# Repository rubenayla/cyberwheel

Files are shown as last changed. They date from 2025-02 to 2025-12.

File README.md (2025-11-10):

<p align="center">
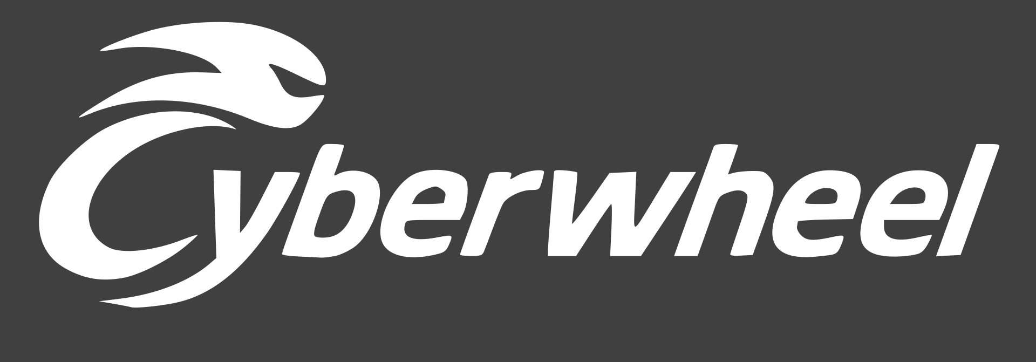
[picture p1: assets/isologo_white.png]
Cyberwheel Logo
  
</p>

# CYBERWHEEL

Open-source electric unicycle hardware and firmware.

## 📖 Documentation

Visit our documentation site: **[https://rubenayla.github.io/cyberwheel/](https://rubenayla.github.io/cyberwheel/)**

## 🎥 Pitch Video

Watch our project pitch: **[https://youtu.be/mN5FoosNMC0](https://youtu.be/mN5FoosNMC0)**

## Purpose
Make electric unicycles that are reliable for everyday use: waterproof, impact-resistant, durable over time, and easy to repair.

For this, create an open-source community to design both the Hardware and Firmware, so they can be repaired and modified, free of proprietary restrictions.

## Repository Structure

```
cyberwheel/
├── docs/              # MkDocs documentation source
├── cad/               # CAD files and designs
├── releases/          # Release versions (cw1.0, cw1.1, etc.)
├── battery/           # Battery design files and images
├── assets/            # Images and media
└── references/        # Reference materials and datasheets
```

## Development

### Build documentation locally

```bash
# Install dependencies with uv
uv sync

# Serve docs locally
uv run mkdocs serve

# Build static site
uv run mkdocs build
```

Documentation is automatically deployed to GitHub Pages on push to main.

## License

This project is licensed under the MIT License - see the [LICENSE](LICENSE) file for details.

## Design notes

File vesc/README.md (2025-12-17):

# VESC workspace

Working area for VESC electronics (Little FOCer, balance app, etc). Use this folder for configs, firmware packages, wiring notes, and raw logs. Anything meant for the published site can live in `docs/vesc/` and link back here.

Suggested layout
- `configs/` — VESC Tool motor/app exports plus a short note on firmware/tool version and hardware.
- `firmware/` — downloaded firmware/tool installers, note the matching hardware target (e.g., Little FOCer ≈ VESC 75_300/LFV3).
- `wiring/` — pinouts, harness drawings, connector part numbers.
- `logs/` — RT data, fault dumps, CSV captures.
- `scripts/` — helpers for converting/analyzing configs.

Naming for configs
- `motor-config_<hardware>_<fw>_<date>.xml`
- `app-config_<mode>_<fw>_<date>.xml`
Example: `motor-config_little-focer-v3.1_5.02_2025-03-28.xml`.

Mac + Little FOCer quick notes
- Install VESC Tool for macOS from vesc-project.com; match tool/firmware versions.
- Power the ESC, connect USB-C, pick `/dev/tty.usb*` in VESC Tool, connect, verify hardware before flashing.
- Start with the stable firmware noted in `stuff.md` (v5.02 for Little FOCer V3.1); keep a copy in `firmware/` with a README stating source/version.

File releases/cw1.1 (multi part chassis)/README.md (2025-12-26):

- think about lid assembly from top to bottom
- add platen to screw to pedal hangers
- finish transparent panel section
- add screws

# Data
Distance between pedal hangers is 5in = 127mm

## Dimensions (from cad/equations.txt)
- wheel_space: 80mm (compatible with 2.75in = 69.85mm tires)
- chassis_length: 360mm
- pedal_separation: 84mm
- seal_edge: 18mm
- wheel_diam: 16in
- thick: 2mm
- chassis_height: 240mm
- lid_height: 360mm
- lid_length: 240mm
- side: 60mm

# Current test setup (2025-03)
- Wheel: 16" (~406mm) hub motor
- Battery: 16S pack (test build; 20S is future design)
- Controller: Little FOCer V3.1, FW 6.05

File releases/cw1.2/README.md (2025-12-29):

# cw1.2

## Added parts
- Power pads by CDoucet: https://www.printables.com/model/698500-power-pads-for-euc/files

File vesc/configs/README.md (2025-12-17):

# Configs

Store VESC Tool exports here:
- Motor config XML
- App config XML (balance/PPM/UART/etc.)

For each file, note firmware version, VESC Tool version, hardware revision, motor, and date. Keep a short changelog if you iterate.

XML vs C headers
- Use XML for normal backup/restore and sharing with VESC Tool.
- C header exports are only needed if you embed configs into firmware builds. If you’re not compiling custom firmware, skip the C header saves.

Current files (2025-03):
- `vesc_mcconf.xml`: pulled from Little_FOCer_V3_1 running FW 6.05 (BLE). Note: limits are placeholder (e.g., l_max_vin=57V) and app mode is not balance; treat as “pre-cleanup” reference only.
- `vesc_appconf.xml`: pulled from same session; app_to_use=3 (PPM), not balance. Use as reference, not as a good baseline.

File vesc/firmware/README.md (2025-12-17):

# Firmware

Keep downloaded firmware, tool installers, and USB drivers here with source/URL and date. Label hardware targets clearly (Little FOCer ≈ VESC 75_300/LFV3 target).

Included (Mac):
- `macOS_VCP_Driver/SiLabsUSBDriverDisk.dmg` (Silicon Labs CP210x VCP driver installer, May 2025) and release notes.
  - Approval: In System Settings → Privacy & Security → Driver Extensions, ensure `CP210xVCPDriver (com.silabs.cp210x)` is enabled after install; allow “Silicon Laboratories Inc.” if prompted, then reboot.

Tip: store the exact VESC Tool version used to flash configs so you can reproduce results.

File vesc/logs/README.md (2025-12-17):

# Logs

Store RT data, fault dumps, CSV captures, and screenshots. Note firmware, tool version, hardware, and conditions (battery voltage, motor, load) for each capture.

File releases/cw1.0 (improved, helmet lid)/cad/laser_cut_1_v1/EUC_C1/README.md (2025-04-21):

- material: acero
    > acero porque es barato y fácil de soldar
- espesor: 2mm
- dimensiones: 653x507mm
- longitud total corte aprox: 4640mm
- plegados, todos a 90º:
    - 6 de 400mm
    - 8 de 210mm
- 1 unidad
- ningún acabado especial

# Estimación coste gpt
| Concepto | Parámetros | Cálculo | Coste (€) |
|:---|:---|:---|:---:|
| Material (acero 2 mm) | 47 €/m² | 0.653×0.507 = 0.331 m² → 0.331×47 | 15.56 |
| Corte láser | 50 €/h; 3 500 mm/min | 4 640 mm / 3 500 mm/min = 1.33 min → 1.33/60×50 | 1.11 |
| Plegado | 50 €/h; 1 min por doblez | 14 dobleces = 14 min → 14/60×50 | 11.67 |
| **Subtotal** | | | 28.34 |
| Overhead & margen (30%)| | 28.34×0.30 | 8.50 |
| **Total aproximado**  | | | **36.8**  |

Incluyendo transporte + IVA ~= 60€

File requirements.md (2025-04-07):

# Cyberwheel Design Requirements
## Concept
> WE SHOULD NOT BLAME THE RIDER FOR A SUDDEN UNPREDICTABLE CUTOFF OF THE EUC.
- Foolproof, weatherproof
- Impossible to fry electronics by riding hard
- Impossible to damage battery by riding too cold (leanback and emergency before)
- Leanback angle calculation is central point, function of:
    - Temperatures
    - Voltages
    - Currents
    - As a consequence:
        - Speed
    > To maintain a given guaranteed minimum torque
- Make it perform strict self-tests
- Error states:
    - **Warning**: Just so you know
    - **Alert**: Gradual limits that affect the performance when balancing. Affects leanback
        - Battery overheating, overvoltage, or undervoltage. All will limit the speed. Overheating may limit it to 0.
    - **Emergency**: STOP. Hard leanback. Safety measures
    > For molicel p42a pack: <8.4A, <4.2V, >0ºC, <45ºC. Gradual transfer curve when getting close to these limits, that results in gradual predictable leanback

## Hardware
- The charger will be built into the EUC, with a small vacuum cleaner style cable.
- Crimped connectors?
    > Not just soldered when there’s so much vibration.
- Bolts: Positive locking mechanism
    - > cotter pin, safety wiring, [nylon, prevailing torque, jet, K] lock nuts, tab washers or locking plates.
- Several wires in parallel for redundancy (motor and battery wiring), while being able to detect a single one disconnecting?
    > Maybe unnecessarily complex
- Battery disconnect loop key? (actionable from the outside.)

## Firmware
- Include emergency modes that get triggered for many reasons
- Dynamic calculation of max speed based on battery level, temperature, and other factors.
- Gradual tiltback that asympotically grows in intensity as the max speed is reached.
- 

- State machine?
    - OFF (Not balancing, when put sideways)
    - Balancing (Normal, affected by alerts)
    - Charging
    - Emergency (Balancing but with hard leanback, to speed 0)

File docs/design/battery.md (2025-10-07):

# Battery - Power and Charging

## CHARACTERISTICS
Battery specifications

- ABSOLUTE LIMITS - **20S2P PACK** - Voltage, Current, Temperature
    - The firmware may put other limits depending on voltage, current, and temperature, but these are the limits that won't be exceeded under any condition.
    - **84V** (4.2V * 20), max voltage * series
    - **90A** battery flow (45A * 2), max cont discharge current * parallels (will be limited to a fraction. Charging max is 25A, so probably about 60A discharge)
    - Charge: **16.8A** (8.4A*2), **1.41kW**
    - Discharge: **90A, 7.56kW**
        - Probably limited to **60A, 5kW** for standard BMS

- CELL LIMITS - SAFETY HOLY GRAIL:
    - **Operating Temp: $0ºC$ to $45ºC$**
    - Max continuous charging current: $8.4A$ (-max torque -max speed)
    - MOLICEL INR-21700-P42A ($60=50;=5*3*2*2$)
        - [INR-21700-P42A_datasheet.pdf](../assets/datasheets/INR-21700-P42A_datasheet.pdf)
        - [Detailed datasheet](https://www.molicel.com/wp-content/uploads/INR21700P42A-V4-80092.pdf)
        - LiNiMnCoO2 (NMC) cathode
        - Impedance at 10A DC 1s: $10 m\Omega$
        - $15.5$Wh, $4.2$Ah, $2.5V - 3.6V - 4.2V, 16m\Omega$
        - Discharge:
            - Continuous: `30A`
            - Peak: `45A`
        - Charge (<8.4A, <4.2V):
            - Max continuous: `8.4A`, 2C $(\frac{8.4A}{4.2Ah} = 2h^{-1})$
    - **Max peak charging pulse**:
        - [INR-21700-P42A_power_pulse.pdf](../assets/datasheets/INR-21700-P42A_power_pulse.pdf)

## PACK
- Energy: $40 * 15.5Wh = 620Wh$
- Max continuous power discharge at 3.6V: $40 * 3.6V * 30A = 4320W \approx 6$CV
- Max charge power at 85%SOC, 40ºC: $40 * 4V * 4.2A = 672W$
- EUC Range: $672Wh / 32.5Wh/km = 20km$
    - Current efficiency: $32.5$Wh/km = $117$J/m = $3.25 \frac{kWh}{100km}$

## FIRE
- [FB4LF-500 encapsulator agent, 4L to 1.8kWh](https://youtu.be/NkH7TzFtSP0?si=DRWmJS_XxrlnIuxk)
- [EUC FIRE](https://youtu.be/Oa79go_aUfc)
- https://everythingelectricunicycle.com/electric-unicycle-fire-risk-and-possible-causes-solutions/
- Fire retardant casing (LithiumPrevent):
    - robnor resin to prevent fire.
- Seriously protect + - separation of cells
- Standards to meet:
    - UL94 V-0 for the minimum used material thickness
    - FAR 25.853(a)(1)(i)

## Battery construction diagram and assembly calculations

- 20S3P, **20S2P**, 30S2P
- Estimated lateral space left for the batteries = (Total Width without ankle padding - Wheel hole width - 4 * chassis_thickness - 2 * padding) / 2 = $(200 - 3*25.4 - 4*3 - 2 * 3)/2 = 52.9mm$, so `math.floor(52.9/21) = math.floor(2.52) = 2`. Two layers of stacked cells
- Dimensions of cell pack (20S2P): `10*23 x 2*23 x 2*70 = 230 x 46 x 140 mm`

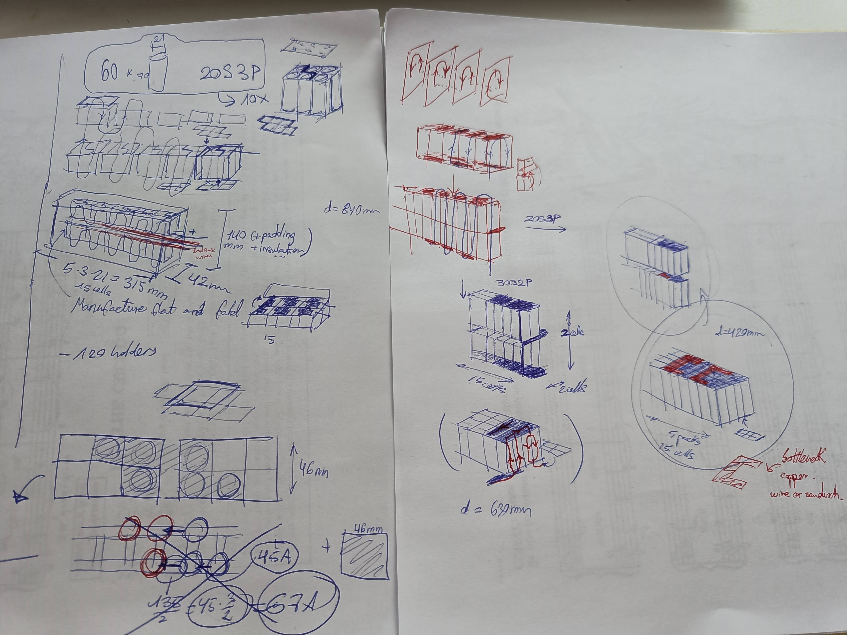
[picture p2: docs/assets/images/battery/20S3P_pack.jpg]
20S3P pack layout

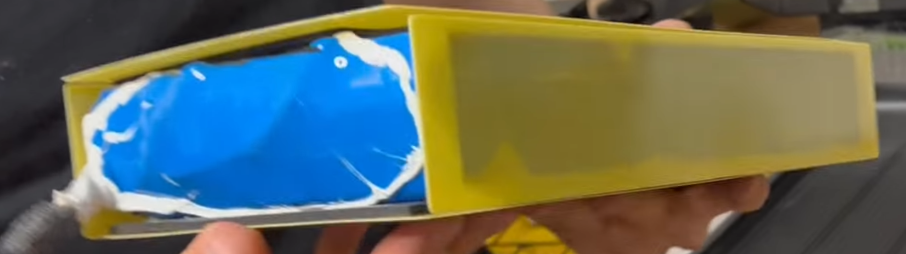
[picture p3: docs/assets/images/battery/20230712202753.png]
Begode EX20S Battery


- Small fans inside the pack

## Cell connection methods
- ~~Bus bars~~ (Hard to connect to the bus bar, hard to assemble)
- ~~Nickel Strip (Spot Welded)~~ (0.15x20mm just 20A, I need 135A)
- **Braided Copper Wire** soldered over Nickel strip
- ~~Busbar Connectors~~ (My cells are not compatible with them)
- **Copper Nickel Sandwich**
    - https://endless-sphere.com/sphere/threads/copper-nickel-sandwich-buses-for-series-connections.108006/
    - The nickel is the resistance that heats up, the current goes through the copper, heat accumulates at the contact points with the nickel, all metal melts, which allows the copper to also connect with the aluminum of the cell terminal below.
- ~~Copper Nickel busbar (tab sheet)~~ (About 150€)
    - Copper with small sections of nickel spot welded where each cell goes. I just have to cut it, place it, and spot-weld it like nickel strips, but with the higher current capacity.

## Braided Copper Wire

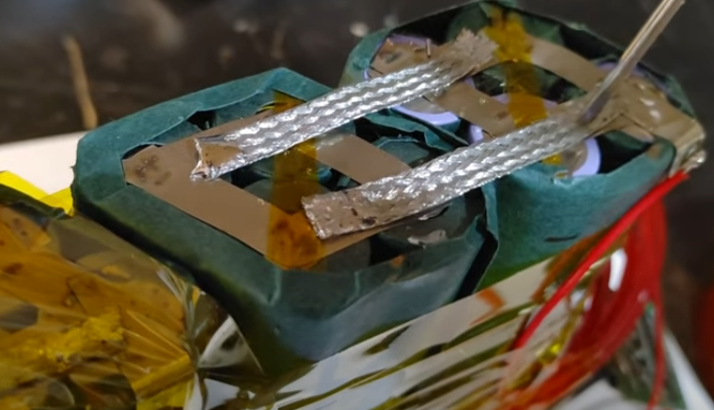
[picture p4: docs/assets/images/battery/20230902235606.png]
Braided copper wire connection


## Cell-level fuses? NO. 1 slow fuse per pack instead

- **All parallel packs have the same current. One fuse fuses all.**
- **A few cells in parallel = a big cell.**
- **Can't short one cell without shorting the others of the pack, so 1 fuse per pack is enough for shorts. However check temp and voltages for other failure modes**
- **These cells can provide 45A, which needs resistance as low as 70mOhm to flow. It's almost a short-circuit. As long as you have R 70mOhm you're within spec, and the power will dissipate outside the cell. If the resistance increases because of damage, I expect that to be gradual and detectable by the BMS to trigger emergency.**
- Fused nickel strip or fuse wire spot welded, about 22mOhm per fuse, calibrated to trip at about 50A?

## Discharge protection of BMS? NO. JUST MONITORING AND ALERTS
- Better let the battery soak up a slight overvoltage for some seconds rather than faceplant due to overvoltage protection after regen.
- Most cutouts are caused by the BMS. You can pull WAY more current than the datasheet allows if it's a short period of time, so don't go crazy cutting power and instead trigger an alarm to stop.
- Adds cost, weight, bottleneck, and complexity. Failure point
- Just monitor the battery and limit the use with the ESC. Protect charging and balance cells. By default ok values allow riding, any error limits or disables balancing (leanback, not cutout)

## Design objectives
- Layout with shorter series paths. Less resistance where the current flows.
    - For this, good layout and copper wires soldered to the nickel strips, then the strips spot welded to the cells.
- Balance between safety of rider (no cutouts) and safety of battery (no fires).
    - BMS with no capability to cut power, but huge safety margin of current, voltage, and temperature of cell limits. When exceeded, trigger alert/warning and force leanback or emergency stop. Fast pulses are not blocked, to prevent falls. The cells can withstand it for a short time. Emergency state must diverge behavior so it can't be rided permanently leaning back out of spec. Force leanback further and further until stop. Stop must happen.
- Assembly: Cells with rigid structure, then squishy stuff, then rigid structure (glass fiber board), then squishy stuff, then rigid container of EUC chassis, then squishy stuff outside of EUC chassis.
- Ports:
    - 230VAC type-f Schuko plug (compatible with Type N even better) like a vacuum cleaner. Usually charge with 110-240VAC 50-60Hz. The charger is built-in. Do not trust random ass external chargers.
    - Allow 12VDC. General range even better.
    - USB-C, with the max 240W (48V 5A). To power electronic devices.
        - I want always 5V by default for dumb devices + negotiation to get more if required. On-Off switch to turn off the 5V is ok.
    - XT90 Anti-spark battery access connector (through BMS)
- Be able to limit the charge to 90% or something. Integrated charge doctor. Cell balancing should still work.

## BMS
Smart, 20S 84V 135A?, charge-side mosfets, balancing, monitor, communications with VESC. More like a BMU with serious control over the VESC.

Even if the BMS is charge only, consider adding a mosfet/relay to open the battery contacts in case of emergency with VESC programming. After emergency state, if speed 0 or time passed, open contactor.

## Notes
Control the temperature by using heaters when cold and fans when hot. Insulate the heat sink in winter to waste less energy.

## References
- [MY REDDIT QUESTION](https://www.reddit.com/r/ElectricUnicycle/comments/161tk0n/bms_recommendation/)
- Search VESC BMS
- Brands
    - ~~[Tiny BMS](https://enepaq.com/product/battery-management-system-bms-30a/)~~ (Not enough voltage)
    - Ennoid (VESC compatible)
        - [Master-slave](https://www.ennoid.me/bms/gen-1)
        - [Single board, Full, 24S](https://www.ennoid.me/bms/ss)
        - [Single board, Charge only, 24S](https://www.ennoid.me/bms/xlite-v3)
    - [Orion](https://www.orionbms.com/products/orion-bms-standard) - $1000 + thermistors + current sensors
    - [MaxKGO](https://maxkgo.com/collections/bms-price/products/maxkgo-bms-4s-24s-15a-only-charge-bms-board)
    - https://www.lithiumbatterypcb.com/product/13s-16s-48v-or-60v-72v-20s-lithium-battery-bluetooth-smart-bms-54-6v-58-4v-67-2v-84v-electric-tricycle-pcb-with-200a-consta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
    - DongGuan Daly - 125A Charge - 250A Discharge

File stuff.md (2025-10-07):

# Reasoning for main location of components -- General configuration
The **inside chassis** of the EUC must hold its own weight, and it won't be subject to crashes or sudden crashes, since the rubber and rim separates it from the ground, and the internal components from crashes around it.

Therefore, a strong and heat conductive material is ideal, not necessarily tough. The sides will be flat, probably with velcro to put pads in any way.

For prototypes with pedal hangers, it will go over them. Like this the geometry is much simpler, the weatherproofing is better, and the motor can be dissassembled much more easily. For large bearing motors, the chassis will be the pedal hanger.

To gain maximum crash resistance, squishy stuff on the outside + rigid stuff inside is ideal, since nothing will penetrate the EUC and the acceleration will be softened. The pads will act as bumpers.

The **outside shell** of the EUC must be optimized for crash resistance, not strength. This highly suggests using GFRP or similar (Fire resistant epoxy?). It should be thermally reflective outside, and insulating, so the battery doesn't get cooked by the sun.

The **Front** will have lights. Since it needs a transparent material with power inside, it's ideal for the antennas too.

At **Top-front** there will be a handle. The handle could be the hinge for a bigger lever that also serves as kickstand and lock. You open it and click it closed around a lamp post or something. Could be two stacked frames like _, that can rotate to form /\, a triangular truss. Rigid grabbing point and good lock to leave it in the street.

The top should be seat-shaped so this could create a conflict.

**Back-down** needs a mudguard. A place for license plate, other info like phone number, and lights.

**Back-up** is the best place for charging ports, since it's the most protected from rain, and unoccupied by other components.

Large in x direction, since we'd need mudguards anyway.

# Observations
- Vents to relieve pressure during fire, while preventing oxygen and water from entering.
- If 60 4Ah Li-Ion cells release all their energy to an 8kg aluminum chassis, it would heat to ~464ºC without melting (Al melts at 660ºC)
    - $\Delta T = \frac{E_{bat}}{m_{Al}*cp_{Al}} = \frac{60*3.7V*4Ah}{8000g*0.9J/gK} = \frac{888 Wh * 3600J/Wh}{7200J/K} = 444K$
- Cascading PIDs
    - use 2 pid loops. One controls the vehicle rotation speed (rate), the other vehicle attitude (angle). This is how many multirotoros (copters) fly, and this is probably the mode that will bring the most stability. It may feel very different in onewheel configuration, not sure if many people like it or not, but this mode can make unicycle pedals feel very hard. 
    - the main (rate loop) does not depend on IMU. It reads RAW gyro data. So less susceptible to IMU tuning, numerical errors, accelerometer noise and jitter.
    - Angle loop depends on IMU, but has much less input.

# Other preferences
- Big inclined pedals inspired by nylonove
- The lighting must be uniform (more light at horizontal angle, to cover more area with uniform brightness), with a servo that takes the angle from the IMU and keeps the lights pointing forwards. https://youtu.be/UxABxSADZ6U
- Wheel easy to remove, downwards, with part of the arm screwed. Disconnect the cables in an accessible place and pull them down.
- Handle + Locker + Kickstand + Mudguard all at once
- Don't screw into plastic.
- Field Oriented Control (FOC) instead of BrushLess DC. No noise more efficiency.
- Connectors
    - XT90S
    - Molex Pico-Clasp (small, locking, populate as many pins as you want)

# Consider in the future
- **If a resistor is added to dump energy instead of regen, the euc will work at temperatures of 60ºC instead of 45ºC (Look [MolicelP42A Datasheet](./datasheets/INR-21700-P42A_datasheet_detailed.PDF))**
- Company: Safe environment and create provoked cutoffs, learn to fall
- Built-in dashcam
- Utilizar la placa principal como cargador? No necesitar placa extra. Hay un coche eléctrico que lo hace.
- Imagine a wheel with an axial flux motor at each side, and a controller board for each motor, working in parallel. Redundancy. If one fails, the other continues working, and the wheel leans back to slow down to a safe speed.
- Recognize when there's no rider (EUC flying alone), and slow down until it stops, instead of just balancing.
- Reverse leanback for breaking
- Tiny wheels to prevent falls after cutoff of normal EUC?

For a redundant system, wheel with 2 hub motors in it, with 2 controllers and batteries, fully independent systems working in parallel. If one fails, the other continues. Even if it fails with short-circuit, motor fuse of the fail side blows (shortcircuit creates a lot of current), while the other compensates and continues.

- Redundant electrical system: computer and power supply, maybe even motor coils (two motor windings in one motor structure, temperature of one doesn't affect the other)
- Storage compartment with small door lock (key or software controlled), to store things in the EUC and leave it locked to a tree or streetlight.
- Hollow bearings?
- No-power mode: when there's no battery available (BMS failure, short, bad contact, etc), go into a mode where balance is done just braking. Power to resistors or the motor itself, no battery.
- Electrically isolated tab gallium nitride mosfet?
- Haptic notification through the pedals when overpower or overspeed.
- Design the shell as a side pad? I don't think so. Flat metal and add pads over it.
- Fingerprint on switch?
- Blinkers on the pedals with buttons over the wheel?
- IMPORTANT, LONG TERM: WHEEL WITH DUAL HUB MOTORS, COILS AT EACH SIDE, DUAL VESC WITH DUAL PROCESSOR, DUAL BATTERY. REDUNDANCY AND BETTER CUTOFF TOLERANCE. VERY RARELY EUC FAIL STUCK. THEY FAIL OFF.

---
# Appendix
- Acronyms
    - EUC: Electric UniCycle
    - SOC: State Of Charge
    - ESC: Electronic Speed Controller
    - VESC: Vedder Electronic Speed Controller
    - BMU: Battery Management Unit
    - BMS: Battery Management System, BMU + switch to disconnect battery
- Reference system: X forwards, Y left, Z up.
- Dimensions:
    - Small hexagon: 30x41(25)
    - Big hexagon: 520 width x 400 height x 300 upper side
    - 18mm of lip to screw and seal the lid is enough.
    - 13cm max width at knee height. (->120mm)
    - Normal 16S battery thickness (with bms and stock padding): ~24mm
    - 2 layers of 2170 cells hexagonally packed mesaure: $21mm*(1+\sqrt(3)) = 39.2mm$
    - Wheel space of 74mm -> comaptible with 2.75in tyres, about 70mm wide. I want ~60mm wide, between 2 and 2.5 inches.
    - EUC Width (Distance between legs): About 24cm with padding, 20cm the bare EUC.
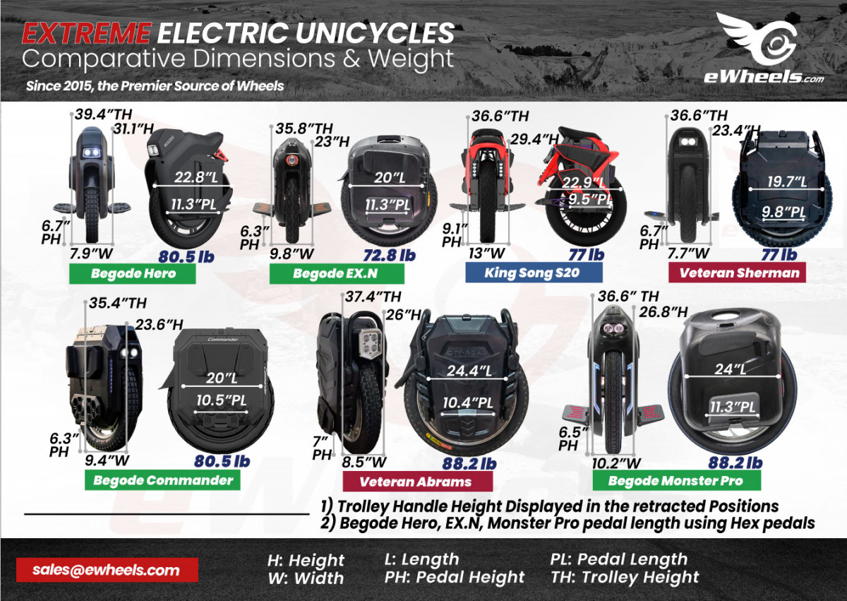
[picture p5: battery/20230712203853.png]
https://content.invisioncic.com/r254450/monthly_2021_09/Extreme-Dimensions-Weight-Comparison-v1.2-1200x851.jpg.7cdc2a8b0f7762dcdecbe4cc21f60eb5.jpg
        - 
    - Pedal height: about 6.5in = 165mm

- Cell Resistance $>100m\Omega$ -> it's bad.
- LFP voltage range: 3.2V nominal, 2.5-3.65V, 2.6-3.6V, 3-3.2V, 
- At the knee, max 13cm distance.

- To have bidirectional USBC charging: **LTC4160*- but the battery is 100V. It's not worth it to be able to charge the unicycle through the bidirectional USB-C PD
- King-Song S22 mosfet package: TO-247
- 4AWG butt connector (crimped)

- Good batteries (high charge rate)
    - **molicel p42a**
    - **Samsung 40t**
    - litech
    - Samsung inr40t

# Protection gear
- [Wrong way full guide](https://youtu.be/KuLZsmgloxY)
- Wristguard
    - 	**[Decathlon](https://www.decathlon.co.uk/p/fit-adult-inline-skating-wrist-guards/_/R-p-6032?mc=8495083)**
    - 	[Ennui](https://www.skatepro.com.pl/116-11108.htm?stockcode=920017)
    - 	[Gloves with wristguards](https://www.gyroriderz.com/products/gants-gyroriderz-avec-proteges-poignets-integres-2-0?lang=en)
- 	Full face downhill helmet (more visibility and lighter than motorcycle). Goggles with 2 layers of glass to prevent fogging, and removable glass.
- 	Downhill kneepads
- 	Mountaineering shoes
- 	Hand mirror

# 
- Iterar, validar, ágil
- El software pensaba basarlo en el proyecto VESC, que está disponible en GitHub, de código abierto, y se podrían hacer mejoras sin empezar desde cero, teniendo electrónica compatible.
- Luego hay cuestiones de seguridad relacionadas con la batería. Si se prioriza la seguridad de la batería, puede haber cortes de potencia que hagan peligrar al piloto, y viceversa
- Use the chassis for cooling. 8kg of aluminum with heatsink in wheel hub and giant wheel moving air. Tape the heatsink in winter if the temperature gets too low.
- use this fuse? Fuse (135A max peak, allow it for 60 seconds, 270A for 1S)
    - UL Class T fuse 300VAC 200A (High-current, fast acting)
- Tienda hacen baterias: https://es.wallapop.com/user/hgomezh-426221412

#
Batería mide 30x9x11, con una caja de esas dimensiones internas me cabe. Algo de margen y poco espumita.
Caja de vino de madera, milwaukee de plastico adaptada, tubo cuadrado pvc 120mm

# 2025-03-07
VESC en Ubuntu.
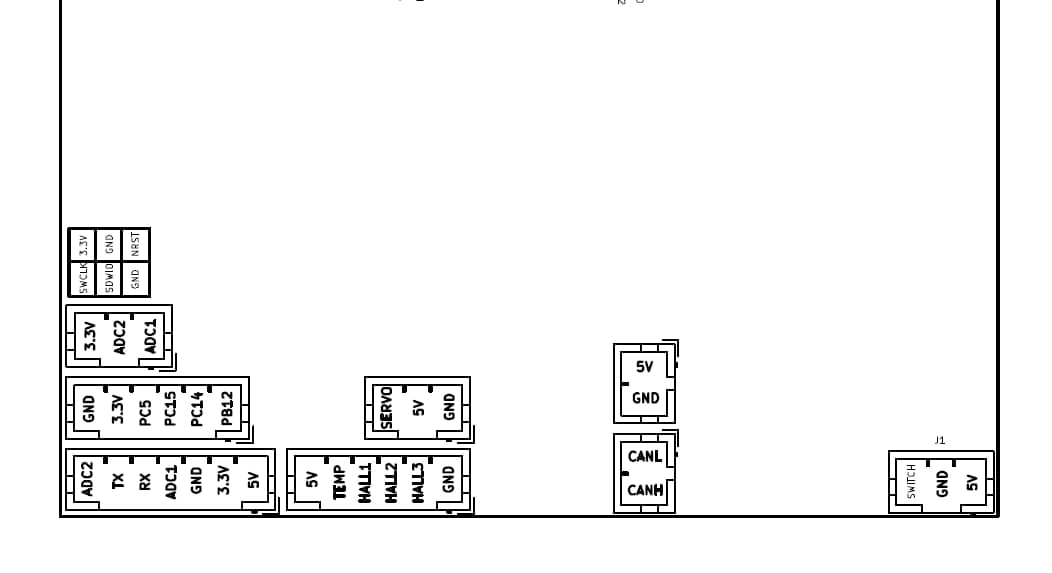
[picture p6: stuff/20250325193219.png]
little focer pinout


The latest stable VESC firmware (v5.02) is the recommended choice for your Little FOCer V3.1 ESC. Users have successfully run v5.02 on this model, whereas the beta (v5.03) is more experimental and may not be fully validated for all hardware revisions.

1. Connect Power (xt60) to vesc
2. USB-C
3. click auto-connect

Motor config
Then limits, current voltage, and important RPM to not damage vesc.

---
Next Level VESC board, noted here
https://tronicsystems.com/products/x12
# To finally remember the difference between isotype, logotype, isologo, imagotype...
iso = symbol
logo = text
type = meaningless thing to add when we need more roots to form the word

Just symbol: iso -> isotype
Just text: logo -> logotype
Symbol and text as single entity: iso + logo -> isologo (not isologotype)
Symbol + Text together: Just an image -> imagotype

# 2025-03-25
Using VESC 6.05 in smartphone app (commit e3d25e96)
PROBLEM! I can configure roll angle errors, but it just continues running with state: fault

- try sensorless, see the difference. maybe the hall sensors are bad?

# 
- Sensors:
    - Motor temperatures and voltages
        - 6 wires: +,-,temp,3halls
    - Mosfet and pcb temperatures and voltages
    - Chassis temp
    - Internal humidity or pressure (detect crashes?)
    - Measure grounding, isolation?

# Pseudocode for the state machine
def continuous_monitoring():
```python
if running:
    # BATTERY TEMP CHECKS
    if (T_bat_C < -40) or (T_bat_C > 60): # Discharge temp limits
        emergency("Battery temperature error") # Hard leanback to 0
    elif T_bat_C > 40:
        alert(T_bat_C, "Alert battery too hot") # Show alert, run fan, limit speed (to limit power for a given acceleration)
    elif T_bat_C < 5:
        alert(T_bat_C, "Alert battery too cold") # Show alert, run heater, limit speed
    
    # MOTOR TEMPERATURE CHECKS
    if (T_mot > ?):
        emergency("Motor temperature error")
    elif (T_mot > ?):
        alert(T_mot, "Alert motor too hot") # Show alert, limit speed
    
    # MOSFET TEMPETAURE CHECKS
    if (T_mos > ?):
        emergency("Mosfet temperature error")
    elif (T_mos > ?):
        alert(T_mos, "Alert mosfets too hot") # Show alert, limit speed
    
    # BATTERY VOLTAGE CHECKS (State Of Charge)
    if (V_bat > ?):
        emergency("Battery overvoltage")
    elif (V_bat > ?):
        alert(V_bat, "Alert battery overvoltage")
    
    # BATTERY CURRENT CHECKS
    if (I_bat > ?):
        emergency("Battery overcurrent")
    elif (I_bat > 135):
        alert(I_bat, "Alert battery overcurrent")
    
    # Alert limiting power when low voltage
    # Look at INR-21700-P42A_power_pulse.pdf to calculate V_bat and T_bat -> max_current -> max_torque -> max_speed
    if (V_bat < ? about 2.8)
        alert(V_bat, "Alert battery undervoltage")

    # TODO undervoltage protection when accelerating?
elif stopped:
    if (T_bat_C < -40) or (T_bat_C > 60): # Discharge temp limits
        emergency("Temperature error")
    elif charger_connected:
        if T_bat_C <= 0: # too low
            activate_heater_from_charger()
            alert("Too cold to charge. Heating battery...")
        elif T_bat_C > 40: # too high
            alert("Cannot charge, too hot. Max cell temp is 45ºC")
        else:
            ok # charge at 4.2A max, 4V 88% SOC()
    else: # charger not connected
        if T_bat_C <= 0:
            activate_heater_from_battery()
            alert("Too cold to run, heating battery...")
        else:
            ok # but activate alert to keep heating if close to 0ºC, up to about 10ºC?
```

# Tyre
I want a balanced offroad capable 18x3 tire (18 diam, 3 width), with a motor like the C30, 84V, in the range of 2500W

- Consider
    - Schinko 244, Kenda K262, CST C186 (all
    14-2,75)
    - **Kenda K262 14-2,75in rim**
        - Sherman and EXN, 80€, with 14-2.75 rim, 
    - **CST C186 14-2,75in rim**
        - 42€, enduro, trial, with tube, 1.96kg, Brand CST, Profile C186, with 14-2.75 rim, 
    - **Heidenau K66 80/90-14**, 80mmx72mm-14in
        - 62€
    - Michelin City Pro 80/90-14 46P
        - 32€

# stuff
- [High Voltage Inter Lock](https://youtu.be/BC1zCC7CeX8)

- V13 parts:
    - Raptor controller
    - Potted battery
    - Redundant Hall sensors

# data about 16s batteries i have for testing
16s, assume 1.5Ah each, 1.5Ah battery
wheel diam 14in, 350mm

# ideal motor for little focer
i want high torque, not high speed, 20s 84V,

# 2025-10-07 - Refloat Configuration Troubleshooting (VESC 6.05, Little FOCer V3.1)

## Problem
After installing Refloat package and running motor + IMU calibration, the EUC would not balance. Motor would spin in manual mode, but balance app wouldn't engage.

## Symptoms
- RT Data (main VESC): No faults (FAULT_CODE_NONE)
- Refloat APPUI: State showed "Ready" but wouldn't transition to balancing
- Requested current: always 0A (-.--A)
- Filtered current: changed slightly when tilted
- IMU: Working correctly, detecting inclination
- Motor: Worked in manual control mode

## What We Tried (and didn't work)

### 1. SimpleStart Configuration
- **Location:** Refloat Cfg → Startup → SimpleStart
- **Action:** Enabled SimpleStart (should bypass sensor requirements for EUC without footpads)
- **Result:** No change - still showed "Ready" but didn't balance
- **Why it didn't work:** SimpleStart alone isn't enough - other settings block engagement

### 2. Startup Pitch Tolerance
- **Location:** Refloat Cfg → Startup → Startup Pitch Tolerance
- **Action:** Tried increasing tolerance to ±10° or ±15°
- **Result:** No change
- **Why:** Not the issue - IMU was reading correctly

### 3. Startup Click Current
- **Location:** Refloat Cfg → Startup → Startup Click Current
- **Action:** Increased to 3-5A for motor engagement pulse
- **Result:** No effect
- **Why:** Not the root cause - motor wasn't even trying to engage

### 4. Roll Angle Fault
- **Previous issue from 2025-03-25:** Had roll angle errors causing fault state
- **This time:** No faults showing, so not the same issue
- **Note:** For EUC (not onewheel), roll faults might trigger incorrectly - consider disabling

### 5. App Configuration Investigation
- **Confusion:** Initially looked at App Cfg → ADC (wrong place!)
  - ADC app is for throttle control (e-bike, RC car) - NOT for balance
  - Keep "App to Use" = "No App" for now (will need to change to "Balance" later)
- **Also checked:**
  - PAS (Pedal Assist System) - irrelevant for EUC
  - PPM, UART options - not needed for balance

## Key Findings

### The Missing Piece: Safe Start Setting
- **Location:** Refloat Cfg → Startup → Safe Start
- **Was set to:** "Regular" (waiting for footpad sensor engagement)
- **Should be:** "Disabled" (for EUC without footpad sensors)
- **Action taken:** Set to "Disabled" and wrote configuration
- **Result:** STILL DIDN'T WORK (as of writing this)

### Understanding the App Selection
- **Important discovery:** VESC needs an "App" selected to run autonomous control
- **App Cfg → General → "App to Use"** must be set to **"Balance"** for Refloat to work
- Manual mode bypasses app selection (for motor testing only)
- Current setting: "No App" - explains why it won't balance!
- **Options available:**
  - No App (current - only manual control works)
  - PPM (RC receiver input)
  - ADC (analog throttle)
  - UART (serial communication)
  - Balance ← **NEED THIS ONE**
  - PPM and UART

## Configuration That Should Work (untested as of writing)
1. ✓ Motor calibration done
2. ✓ IMU calibration done
3. ✓ Refloat package installed
4. ✓ SimpleStart enabled (Refloat Cfg → Startup)
5. ✓ Safe Start = Disabled (Refloat Cfg → Startup)
6. ⚠️ App to Use = "Balance" (App Cfg → General) - **LIKELY THE FIX**
7. Write motor configuration
8. Test

## Important Lessons Learned

### 1. Refloat vs Balance vs App Settings
- **Refloat** = Package that enhances/replaces the Balance app
- **Balance** = The VESC application mode for self-balancing
- **App to Use** = Must be set to "Balance" for Refloat to actually run
- These are separate settings that all need to be configured correctly

### 2. ADC Confusion
- **Refloat ADC inputs** (for footpad sensors) ≠ **App Cfg → ADC** (for throttle control)
- Don't touch App Cfg → ADC - keep it "Off"
- Refloat has its own ADC/switch settings in Refloat Cfg

### 3. SimpleStart is Not Enough
- Enabling SimpleStart doesn't automatically bypass all safety checks
- Also need:
  - Safe Start = Disabled
  - Probably other switch/sensor settings
  - App to Use = Balance

### 4. RT Data Navigation
- **Main RT Data** (VESC): Shows motor/electrical data (voltage, current, RPM, faults)
- **Refloat APPUI** (Refloat Cfg → APPUI): Shows balance-specific data (State, Pitch, Roll, etc.)
- Need to use Refloat APPUI for balance troubleshooting

## Previous Issue Reference (2025-03-25)
- Using VESC 6.05 in smartphone app (commit e3d25e96)
- Problem: Could configure roll angle errors, but continued running with state: fault
- Resolution: Not documented (need to note solution if this happens again)

## USB Driver Notes (related troubleshooting)
- Little FOCer V3.1 uses Silicon Labs CP2102 USB-to-UART chip
- macOS needs CP210x VCP driver installed
- Download from: https://www.silabs.com/developers/usb-to-uart-bridge-vcp-drivers
- After install + reboot: `/dev/tty.SLAB_USBtoUART` appears
- **Why custom driver needed?**
  - CP2102 doesn't use USB CDC (Communications Device Class) standard
  - USB is universal physically, but each chip needs translation driver
  - CDC-compatible chips work without custom drivers, but CP2102 predates widespread CDC adoption
  - Tradeoff: Better performance/reliability vs one-time driver install

## THE SOLUTION ✓
**Setting App to Use = "Balance" worked on first try!**

After changing App Cfg → General → "App to Use" from "No App" to "Balance" and writing configuration, the EUC immediately started balancing.

### Issue After Fix: Oscillation at ~5Hz
- **Symptom:** EUC balances but oscillates/wobbles at approximately 5Hz
- **Cause:** PID tuning not optimized for this motor/wheel combination
- **Solution needed:** Tune PID parameters in Refloat Cfg

## Normal PID Values for EUC (Refloat)
**NOTE:** These values assume standard Refloat scaling (0-10 typical range). Your version might use different scaling (0-100 or 0-1000). Check what scale your settings use!

### Expected Starting Values (Standard Scaling):
- **P (Proportional):** 2.0 - 3.0
  - Range: 1.5 - 4.0
  - Effect: Response speed. Too high = oscillation, too low = sluggish/won't balance

- **I (Integral):** 0.03 - 0.05
  - Range: 0.02 - 0.08
  - Effect: Corrects steady-state error. Too high = slow oscillation, too low = drift

- **D (Derivative):** 0.05 - 0.10 (for more rigidity, can go to 0.15-0.20)
  - Range: 0.01 - 0.20
  - Effect: Dampens oscillations AND adds rigidity. Too high = jittery, too low = overshoots/oscillates

### Current Setup (2025-10-07):
- **D set to ~20** - Either:
  - Version uses different scaling (20 might equal 0.2 in standard scaling), OR
  - Value is extremely high (needs verification next session)
- **To test next session:** Try standard values above and see if behavior changes
- Document actual P, I, D values being used and their effects

### For 5Hz Oscillation Fix:
- **Primary fix:** Adjust P and D gains
- **Secondary option:** Add filtering/lower filter frequency
- Adjust in small increments (10-20% at a time)
- Test after each change

### Tuning Process:
1. Start with P: Reduce until oscillation stops, then increase until barely starts again
2. Add D: Increase to dampen remaining oscillation
3. Fine-tune I: Adjust for steady-state position holding
4. Iterate

## Next Steps (when resuming)
1. ~~Confirm App to Use = "Balance" in App Cfg → General~~ ✓ DONE - WORKED!
2. Tune PID values to eliminate 5Hz oscillation
3. Document final PID values that work for this setup

## Firmware & Hardware
- VESC Firmware: 6.05
- Controller: Little FOCer V3.1 (84V 20S capable)
- Package: Refloat (latest version as of Oct 2025)
- Motor: [Add motor model if known]
- Battery: 16S test pack (1.5Ah cells, ~60V nominal)

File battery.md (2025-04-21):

# Battery - Power and charging

## CHARACTERSITICS

- ABSOLUTE LIMITS - **20S2P PACK** - Voltage, Current, Temperature
    - The firmware may put other limits depending on voltage, current, and temperature, but these are the limits that won't be exceeded under any condition.
    - **84V** (4.2V * 20), max voltage * series
    - **90A** battery flow (45A * 2), max cont discharge current * parallels (will be limited to a fraction. Charging max is 25A, so probably about 60A discharge)
    - Charge: **16.8A** (8.4A*2), **1.41kW**
    - Discharge: **90A, 7.56kW**
        - Probably limited to **60A, 5kW** for standard BMS

- CELL LIMITS - SAFETY HOLY GRAIL:
    - **Operating Temp: $0ºC$ to $45ºC$**
    - Max continuous charging current: $8.4A$ (-max torque -max speed)
    - MOLICEL INR-21700-P42A ($60=50;=5*3*2*2$)
        - [INR-21700-P42A_datasheet.pdf](datasheets/INR-21700-P42A_datasheet.pdf)
            - https://www.litechpower.com/htmledit/uploadfiles//20210628200957892.PDF
        - [INR-21700-P42A_datasheet_detailed.pdf](datasheets/INR-21700-P42A_datasheet_detailed.pdf)
            - https://www.molicel.com/wp-content/uploads/INR21700P42A-V4-80092.pdf
        - LiNiMnCoO2 (NMC) cathode
        - Impedance at 10A DC 1s: $10 m\Omega$
        - $15.5$Wh, $4.2$Ah, $2.5V - 3.6V - 4.2V, 16m\Omega$
        - Discharge:
            - Continuous: `30A`
            - Peak: `45A`
        - Charge (<8.4A, <4.2V):
            - Max continuous: `8.4A`, 2C $(\frac{8.4A}{4.2Ah} = 2h^{-1})$
    - **Max peak charging pulse**:
        - [INR-21700-P42A_power_pulse.pdf](datasheets/INR-21700-P42A_power_pulse.pdf)
            - https://forum.esk8.news/t/molicel-p42a-max-pulsed-charging-current-specs-for-regen-settings/46147

## PACK
- Energy: $40 * 15.5Wh = 620Wh$
- Max continuous power discharge at 3.6V: $40 * 3.6V * 30A = 4320W \approx 6$CV
- Max charge power at 85%SOC, 40ºC: $40 * 4V * 4.2A = 672W$
- EUC Range: $672Wh / 32.5Wh/km = 20km$
    - Current efficiency: $32.5$Wh/km = $117$J/m = $3.25 \frac{kWh}{100km}$

## FIRE
- [FB4LF-500 encapsulator agent, 4L to 1.8kWh](https://youtu.be/NkH7TzFtSP0?si=DRWmJS_XxrlnIuxk)
- [EUC FIRE](https://youtu.be/Oa79go_aUfc)
- https://everythingelectricunicycle.com/electric-unicycle-fire-risk-and-possible-causes-solutions/
- Fire retardant casing (LithiumPrevent):
    - robnor resin to prevent fire.
- Seriously protect + - separation of cells
- Standards to meet:
    - UL94 V-0 for the minimum used material thickness
    - FAR 25.853(a)(1)(i)

## Battery construction diagram and assembly calculations

- 20S3P, **20S2P**, 30S2P
- Estimated lateral space left for the batteries = (Total Width without ankle padding - Wheel hole width - 4 * chassis_thickness - 2 * padding) / 2 = $(200 - 3*25.4 - 4*3 - 2 * 3)/2 = 52.9mm$, so `math.floor(52.9/21) = math.floor(2.52) = 2`. Two layers of stacked cells
- Dimensions of cell pack (20S2P): `10*23 x 2*23 x 2*70 = 230 x 46 x 140 mm`


Begode EX20S Battery

- Small fans inside the pack

## Cell connection methods
- ~~Bus bars~~ (Hard to connect to the bus bar, hard to assemble)
- ~~Nickel Strip (Spot Welded)~~ (0.15x20mm just 20A, I need 135A)
- **Braided Copper Wire** soldered over Nickel strip
- ~~Busbar Connectors~~ (My cells are not compatible with them)
- **Copper Nickel Sandwich**
    - https://endless-sphere.com/sphere/threads/copper-nickel-sandwich-buses-for-series-connections.108006/
    - The nickel is the resistance that heats up, the current goes through the copper, heat accumulates at the contact points with the nickel, all metal melts, which allows the copper to also connect with the aluminum of the cell terminal below.
    - 
- ~~Copper Nickel busbar (tab sheet)~~ (About 150€)
    - Copper with small sections of nickel spot welded where each cell goes. I just have to cut it, place it, and spot-weld it like nickel strips, but with the higher current capacity.

## Braided Copper Wire



## References
- [18650 Lithium Ion Battery Identification Reference](https://docs.google.com/spreadsheets/d/1fYjDxxCJXfm2wdpGWCaOUGq8V8TOEgsnplHQa4YQpRQ/htmlview)
- [How To Make A Lithium Battery Pack With 18650 Cells](https://youtu.be/3dD5KmM8ciU)
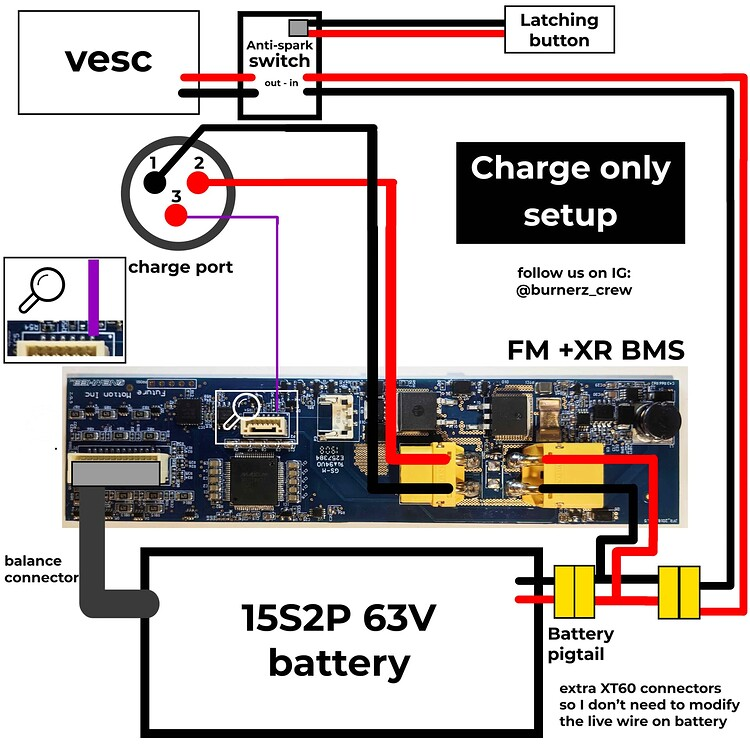
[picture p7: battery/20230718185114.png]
Charge-only BMS wiring
- 
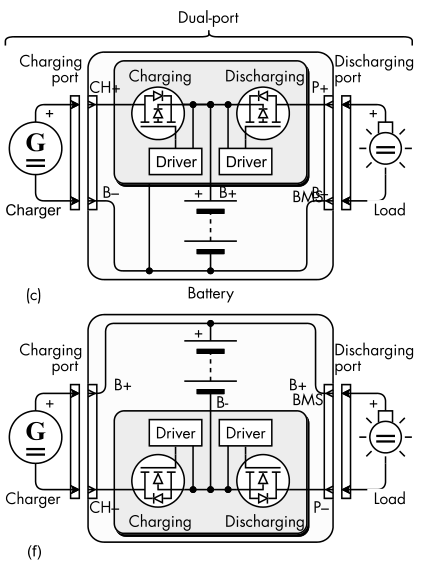
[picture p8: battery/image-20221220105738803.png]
DIAGRAM. ONLY CHARGE PROTECTION. ALWAYS MONITORING. Actually one side allows only safe charge while the other monitors but doesn't cut charge and discharge
- 

## Cell-level fuses? NO. 1 slow fuse per pack instead

- **All parallel packs have the same current. One fuse fuses all.**
- **A few cells in parallel = a big cell.**
- **Can't short one cell without shorting the others of the pack, so 1 fuse per pack is enough for shorts. However check temp and voltages for other failure modes**
- **These cells can provide 45A, which needs resistance as low as 70mOhm to flow. It's almost a short-circuit. As long as you have R 70mOhm you're within spec, and the power will dissipate outside the cell. If the resistance increases because of damage, I expect that to be gradual and detectable by the BMS to trigger emergency.**
- Fused nickel strip or fuse wire spot welded, about 22mOhm per fuse, calibrated to trip at about 50A?

## Discharge protection of BMS? NO. JUST MONITORING AND ALERTS
- Better let the battery soak up a slight overvoltage for some seconds rather than faceplant due to overvoltage protection after regen.
- Most cutouts are caused by the BMS. You can pull WAY more current than the datasheet allows if it's a short period of time, so don't go crazy cutting power and instead trigger an alarm to stop.
- Adds cost, weight, bottleneck, and complexity. Failure point
- Just monitor the battery and limit the use with the ESC. Protect charging and balance cells. By default ok values allow riding, any error limits or disables balancing (leanback, not cutout)

- Objectives
    - Layout with shorter series paths. Less resistance where the current flows.
        - For this, good layout and copper wires soldered to the nickel strips, then the strips spot welded to the cells.
    - Balance between safety of rider (no cutouts) and safety of battery (no fires).
        - BMS with no capability to cut power, but huge safety margin of current, voltage, and temperature of cell limits. When exceeded, trigger alert/warning and force leanback or emergency stop. Fast pulses are not blocked, to prevent falls. The cells can withstand it for a short time. Emergency state must diverge behavior so it can't be rided permanently leaning back out of spec. Force leanback further and further until stop. Stop must happen.
    - Assembly: Cells with rigid structure, then squishy stuff, then rigid structure (glass fiber board), then squishy stuff, then rigid container of EUC, then squishy stuff outside of EUC chassis.
    - Ports:
        - 230VAC type-f Schuko plug (compatible with Type N even better) like a vacuum cleaner. Usually charge with 110-240VAC 50-60Hz. The charger is built-in. Do not trust random ass external chargers.
        - Allow 12VDC. General range even better.
        - USB-C, with the max 240W (48V 5A). To power electronic devices.  
            - I want always 5V by default for dumb devices + negotiation to get more if required. On-Off switch to turn off the 5V is ok.
        - XT90 Anti-spark battery access connector (through BMS)
    - Be able to limit the charge to 90% or something. Integrated charge doctor. Cell balancing should still work.

## BMS
Smart, 20S 84V 135A?, charge-side mosfets, balancing, monitor, communications with VESC**. More like a BMU with serious control over the VESC.

Even if the BMS is charge only, consider adding a mosfet/relay to open the battery contacts in case of emergency with VESC programming. After emergency state, if speed 0 or time passed, open contactor.

## Notes
Control the temperature by using heaters when cold and fans when hot. Insulate the heat sink in winter to waste less energy.

## References
- [MY REDDIT QUESTION](https://www.reddit.com/r/ElectricUnicycle/comments/161tk0n/bms_recommendation/)
- Search VESC BMS
- Brands
    - ~~[Tiny BMS](https://enepaq.com/product/battery-management-system-bms-30a/)~~ (Not enough voltage)
    - Ennoid (VESC compatible)
        - [Master-slave](https://www.ennoid.me/bms/gen-1)
        - [Single board, Full, 24S](https://www.ennoid.me/bms/ss)
        - [Single board, Charge only, 24S](https://www.ennoid.me/bms/xlite-v3)
    - [Orion](https://www.orionbms.com/products/orion-bms-standard) - $1000 + thermistors + current sensors
    - [MaxKGO](https://maxkgo.com/collections/bms-price/products/maxkgo-bms-4s-24s-15a-only-charge-bms-board)
        - https://youtu.be/1FJCuASENxU?si=YWHiunpEP1Cwen0X
    - https://www.lithiumbatterypcb.com/product/13s-16s-48v-or-60v-72v-20s-lithium-battery-bluetooth-smart-bms-54-6v-58-4v-67-2v-84v-electric-tricycle-pcb-with-200a-consta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
    - DongGuan Daly - 125A Charge - 250A Discharge
        - https://youtu.be/1KXRtSAv37A?si=wz8mnM9c49Kpiw95

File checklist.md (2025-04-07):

# Safety
- [ ] Dynamic forces have been simulated
- [ ] Dynamic forces have been tested
- [ ] Fatigue tests have been performed (riding x km in rough terrain should work)
- [ ] Waterproofing test
    - The chassis keeps positive and negative pressure inside. The lighting panel should break/melt in case of fire, so it won't be a bomb.
- [ ] Battery at 100%, go fast and try sudden braking
    - Does the battery suffer overvoltage?
    - What is the maximum deceleration achieved? (consider a minimum threshold to validate it)
    > Alternatives are controlled short of motor wires, without regen. An external resistor (probably better the first approach)
    > This affects braking power but also ability to ride in <0ºC, where the battery can't charge (the anode gets covered in metallic lithium layer that can cause a short circuit)
- [ ] Record at x speed and calculate the torque being applied. Must get over a minimum

# 
- [ ] The documentation fully explains the maintenance and safety procedures

> Could be cool to record these tests and let people propose and vote new tests to be performed.

## To consider
- [ ] Crazy test: Unplug the battery
    - It should enter emergency mode, spend all power available for leanback, and start braking with pwm control, dumping the energy slowly to the motor coils, in a stable deceleration with enough leeway to perform balancing.

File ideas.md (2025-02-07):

# Self-levelling lights
Needs algorithm that estimates ground inclination

---
# Doubt: What affects the wobble stability of an EUC?

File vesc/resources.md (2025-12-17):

# Little FOCer V3.1 / VESC resources (2025-03)

Purpose: quick reference for hardware docs, firmware, tools, and reliable guides for the Little FOCer V3.1 (20S, ~84V) and VESC firmware.

Official / manufacturer
- Little FOCer V3.1 product page: https://customwheel.shop/high-voltage-vesc-motor-speed-controllers/little-focer-v31-vesc-84v-20s-chassispanel-mount
- Tronic Systems (designer): https://tronicsystems.com/products/x12 (general VESC info, support)
- VESC Project home: https://vesc-project.com/
- VESC documentation: https://vesc-project.com/documentation
- VESC Tool downloads: https://vesc-project.com/vesc_tool (Mac/Win/Linux installers; version shown in-app under Help → About)

Firmware / hardware target
- Hardware target: Little FOCer uses the VESC “75_300 / LFV3” target (same family as VESC 75/300). Pick this when flashing.
- Stable baseline commonly used on LFV3: firmware 5.02/5.03 (older), 6.05 (newer). Verify compatibility in the VESC forum before flashing newer than 6.05; keep a copy of the previously working firmware in `vesc/firmware/`.
- Upgrade/downgrade tip: after flashing, reconnect, read all settings, and re-run motor detection if the major firmware version changes. Keep known-good motor/app configs exported before flashing.

Setup / how-to (Mac + LFV3)
- Install VESC Tool for macOS from the link above (free tier works for USB). Check version in Help → About; match configs/firmware to that version.
- Connect: power the LFV3 (XT60), USB-C to Mac, select `/dev/tty.usb*` → Connect → Read FW/Hardware.
- Flash: choose hardware 75_300/LFV3 → upload firmware → wait for reboot → reconnect.
- Configure: run motor detection, set voltage/current limits for 20S pack, set RPM limits to protect the controller, then configure App (Balance/UART/PPM). Save motor and app configs to `vesc/configs/` with firmware and date in the filename.
- Logging: use VESC Tool RT Data to capture CSVs for tuning; store in `vesc/logs/` with notes on battery voltage, load, and terrain.

Community guides / references
- Balance App info (VESC site): https://vesc-project.com/node/2689
- VESC Balance Telegram group: https://t.me/joinchat/JP0KNxbguWM5KhHrT5_CYA
- VESC Tool setup video: https://youtu.be/lDuV8cnPRmI
- VESC fault codes list: https://vesc-project.com/node/3941
- rESCue safety project: https://github.com/thankthemaker/rESCue (for fault handling ideas)

What to store here
- Firmware/tool installers (with version and source) in `vesc/firmware/`.
- Exported motor/app configs per firmware in `vesc/configs/` (name them `motor-config_little-focer-v3.1_<fw>_<date>.xml` etc.).
- Pinouts, harness drawings, connector BOM in `vesc/wiring/`.
- RT data, fault logs, screenshots in `vesc/logs/`.

CLI (headless) usage
- Binary: `~/Applications/VESC Tool.app/Contents/MacOS/VESC Tool` (Mac install path you’re using).
- Common commands (add `--offscreen` to avoid UI):
  - `--vescPort <port>`: set serial port (e.g., `/dev/tty.usbmodemXXXX` or `/dev/tty.SLAB_USBtoUART`).
  - `--getMcConf <file>` / `--setMcConf <file>`: read/write motor config XML.
  - `--getAppConf <file>` / `--setAppConf <file>`: read/write app config XML.
  - `--queryDeviceFwParams`: print HW/FW info.
  - `--debugOutFile <file>`: log debug output.
Examples:
```bash
~/Applications/VESC\ Tool.app/Contents/MacOS/VESC\ Tool \
  --offscreen --vescPort /dev/tty.usbmodemXXXX \
  --getMcConf vesc/configs/motor-config_little-focer-v3.1_6.05_16s_16in.xml

~/Applications/VESC\ Tool.app/Contents/MacOS/VESC\ Tool \
  --offscreen --vescPort /dev/tty.usbmodemXXXX \
  --getAppConf vesc/configs/app-config_balance_6.05_16s_16in.xml

~/Applications/VESC\ Tool.app/Contents/MacOS/VESC\ Tool \
  --offscreen --vescPort /dev/tty.usbmodemXXXX \
  --queryDeviceFwParams
```
Use the port that appears when the LF is connected (`ls /dev/tty.* /dev/cu.*`).

Balance PID tuning notes (2025-12) for 16S, 16" wheel, Little FOCer V3.1, FW 6.05
- IMU: oscillation (~4–5 Hz) on stand was fixed by setting IMU profile to “Balance Unicycle” (was Default).
- Wheel: set `si_wheel_diameter` to 0.406 m for 16".
- Typical community ranges: Angle P 0.8–1.5, Angle D 0.1–0.6 (higher if filtered), Rate P 0.05–0.15, Rate D 0.1–0.25, D LP 5–15 Hz, Loop 500–1000 Hz, I ~0.
- Our tests: high Angle D (up to ~6) reduced sway more than low D. Adding Rate loop damping helps:
  - A workable direction to try: Angle P ~1.0, Angle D 5–6, Rate P ~0.1, Rate D ~0.2, D LP 10–12 Hz (HP 0), Loop 1000 Hz, I=0. If too harsh/noisy, back Angle D toward 4–5 and/or tighten D LP to ~8 Hz; if wobble persists, bump Rate D ≤0.25. If still stubborn, try Loop 500 Hz for phase margin.
  - Lower-gain set that reduced self-oscillation: Angle P ~0.6–1.0, Angle D ~0.1–0.3, Rate P ~0.05–0.1, Rate D ~0.12–0.2, D LP 5–10 Hz.
- Save known-good configs to XML (`vesc/configs/`) once stable.

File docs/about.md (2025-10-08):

# About Cyberwheel

Cyberwheel is an open-source electric unicycle project focused on creating accessible, customizable, and educational hardware and firmware for personal electric vehicles.

## Project Goals

- **Open Source**: Making electric unicycle technology accessible to everyone through open hardware and software designs
- **Educational**: Providing a platform for learning about electric vehicles, motor control, and embedded systems
- **Community-Driven**: Building a collaborative environment where enthusiasts can contribute and improve the design
- **Safety-Focused**: Implementing robust safety features and best practices in battery management and motor control

## Contact

For questions, suggestions, or collaboration opportunities, please reach out:

- **Email**: [ruben.jimenezmejias@gmail.com](mailto:ruben.jimenezmejias@gmail.com)
- **GitHub**: [github.com/rubenayla/cyberwheel](https://github.com/rubenayla/cyberwheel)

## Contributing

Contributions are welcome! Please feel free to submit issues, pull requests, or reach out with ideas for improvements.

## License

This project is open source. Please refer to the repository for specific license information.

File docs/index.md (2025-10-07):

# Cyberwheel

## Purpose
Make electric unicycles that are reliable for everyday use: waterproof, impact-resistant, durable over time, and easy to repair.

For this, create an open-source community to design both the Hardware and Firmware, so they can be repaired and modified, free of proprietary restrictions.

[Video Pitch: https://youtu.be/mN5FoosNMC0](https://youtu.be/mN5FoosNMC0)

## Current state
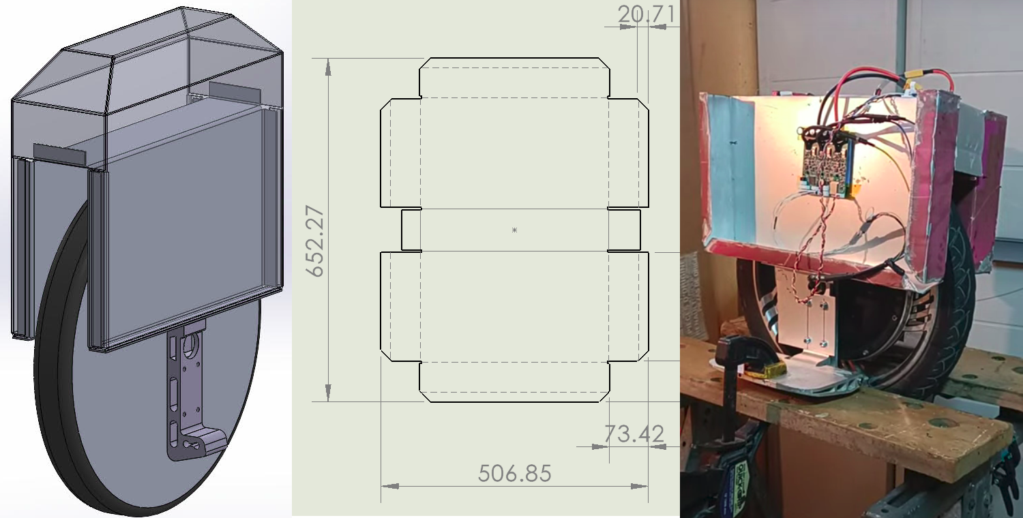
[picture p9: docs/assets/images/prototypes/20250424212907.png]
Current prototype

TODO: Video. Waiting for laser-cut chassis to do new version and tune the PID.

## Why EUCs?
EUCs have a significantly bigger wheel than scooters (16 ~ 18"), which makes them more stable (yeah, It's hard to believe, but trust me), specially in rough terrain. They can go up curbs, down stairs, and sometimes even UP stairs. They're very pleasant to ride. Hands free, it feels like you're floating.

They're way easier to carry around, like a little suitcase, so you can use them to park your car in the outskirts of the city and ride the couple km left to your destination, skipping traffic and parking fees. For short trips, it might even replace your car. Current ones get easily to 90 km/h, and exceed 100 km of range.

## Goals
I want to challenge the idea that, if your EUC cuts out, it's your fault. A well designed EUC should never cut power, even if you try. There must be margin for error.

And this margin includes undervoltage AND overvoltage. Ideas to consider are resistor or motor coil short-circuit braking, instead of dumping to the battery when it's already full.

More on [requirements](./getting-started/requirements.md).

## What's the problem with current EUCs?
Even though current EUCs are very cool and powerful, they're generally not resistant to crashes, the hardware and software is propietary, they can often be damaged by simple rain, can overheat easily with no sensors to prevent it, and have battery fires.

I want to design an EUC that you can trust and repair yourself.

I plan to use a sealed enclosure for the electronics and batteries, increase the redundancy when possible, increase the margins for error, and design the EUC so it's impossible to conceive a cutout as anything but a fatal error.

## Features
- Sealed electronics and battery compartment
    > You can throw it in the sea and won't have to worry about it.
- Use the chassis as a heatsink. Probably an aluminum chassis, or an embedded heat sink.
- The handle will serve as a kickstand, and will unfold to serve as a metal arm that can be used to lock the EUC to a pole. It will also serve as a seat.
- It will have the charger built-in
- Consider self-leveling light that calculate the slope of the road based on the motor current draw and adjust the angle with a simple servo.
- Battery pack with fireproof cover
- Easy to assemble and disassemble

## Target parameters for now
About 50kmh, 80kg rider, hill climbing, 18" or 16", 20s 84V, no suspension, hollow bore motor preferrably
> I think C38 or C30 motors match. Best is C38 high torque

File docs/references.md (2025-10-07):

# References

## EUC Comparisons and Specifications
- [Freshly Charged EUC Comparison Tool](https://freshlycharged.com/euc-comparison-tool/)
- [EUC Comparison Spreadsheet](https://onedrive.live.com/view.aspx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)

## Purchase Sources
- [MyeWheel](https://myewheel.com/)
- [Electric Unicycles EU](https://www.electricunicycles.eu/product_catalog)
- [eWheels Parts](https://ewheels.com/pages/parts#products_categories_row_180)

## DIY and Custom Builds
- [Custom Gotway Monster Build](https://forum.electricunicycle.org/topic/18154-i-made-a-custom-gotway-monster/)
- [DIY Self-Balancing One Wheel Vehicle](https://www.instructables.com/DIY-Self-Balancing-One-Wheel-Vehicle/)
- [Copper-Nickel Sandwich for Current Collectors](https://cellsaviors.com/blog/copper-nickel-sandwich)
- [Wairworthy - Aircraft Build Techniques](https://www.youtube.com/@wairworthy/shorts)

## VESC Resources
- [VESC Project](https://vesc-project.com/)
- [VESC Documentation](https://vesc-project.com/documentation)
- [VESC BLDC GitHub](https://github.com/vedderb/bldc)
- [Balance App Info - VESC](https://vesc-project.com/node/2689)
- [VESC Balance Telegram Group](https://t.me/joinchat/JP0KNxbguWM5KhHrT5_CYA)
- [VESC Balance Tutorial Playlist](https://youtube.com/playlist?list=PLHu3LpOcWhxyn11v0Hx8pvxD1ymyQL4SX&si=PjZiLmkFITcXCBZ9)
- [VESC Tool Setup Tutorial](https://youtu.be/lDuV8cnPRmI)
- [Understanding ESC Operation](https://youtu.be/YV-ee8wA5lI)
- [rESCue Safety Project](https://github.com/thankthemaker/rESCue)
- [VESC Fault Code List](https://vesc-project.com/node/3941)
- [Little FOCer V3.1 ESC 84V 20S](https://customwheel.shop/high-voltage-vesc-motor-speed-controllers/little-focer-v31-vesc-84v-20s-chassispanel-mount)

## Battery Resources
- [Build Massive DIY Battery](https://youtu.be/QMQYfk2RKtU)
- [Detailed Battery Pack Build for E-Skateboard](https://youtu.be/7QjO90LG67g)
- [Second Life Storage](https://secondlifestorage.com/index.php)
- [Inventus Power Custom Battery Packs](https://inventuspower.com/custom-battery-packs/)
- [Formula SAE Electric Battery Management System](https://medium.com/tianyechen-portfolio/formula-sae-electric-battery-management-system-df12e000f457)
- [FS Nottingham 2020 Accumulator](https://youtu.be/4xOo8Uv2nHw?si=mMkoztjvpohZPZ4r)
- [18650 Lithium Ion Battery Identification Reference](https://docs.google.com/spreadsheets/d/1fYjDxxCJXfm2wdpGWCaOUGq8V8TOEgsnplHQa4YQpRQ/htmlview)
- [How To Make A Lithium Battery Pack With 18650 Cells](https://youtu.be/3dD5KmM8ciU)

## Maintenance and General
- [Guide to Electric Unicycle Maintenance 2020](https://www.thecotillion.theater/the-blerg-archive/2020/3/22/the-guide-to-electric-unicycle-maintenance-2020-edition)
- [EUCYou Instagram](https://www.instagram.com/eucyou?)
- [Clark Pads](https://clarkpads.com/)

## Academic Papers
- [IEEE Paper 7860971](https://ieeexplore.ieee.org/document/7860971)
- [IEEE Paper 7861046](https://ieeexplore.ieee.org/document/7861046?section=abstract)

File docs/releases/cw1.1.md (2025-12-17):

# CW1.1 (Multi Part Chassis)

Version 1.1 of the CYBERWHEEL featuring a multi-part chassis design.

## Development Notes
- Think about lid assembly from top to bottom
- Add platen to screw to pedal hangers
- Finish transparent panel section
- Add screws

## Specifications
- Distance between pedal hangers: 5in = 127mm
- Current test setup (2025-03):
  - Wheel: 16" (~406mm) hub motor
  - Battery: 16S pack (current build; 20S is planned for the definitive design)
  - Controller: Little FOCer V3.1, FW 6.05

## Files
See the [releases/cw1.1 (multi part chassis)](../../releases/cw1.1%20(multi%20part%20chassis)/) directory for CAD files and BOM.

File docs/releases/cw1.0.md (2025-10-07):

# CW1.0 (Improved, Helmet Lid)

Version 1.0 of the CYBERWHEEL featuring improvements and a helmet-style lid design.

## Development Notes
- Think about lid assembly from top to bottom
- Add platen to screw to pedal hangers
- Finish transparent panel section
- Add screws

## Specifications
- Distance between pedal hangers: 5in = 127mm

## Files
See the [releases/cw1.0 (improved, helmet lid)](../../releases/cw1.0%20(improved,%20helmet%20lid)/) directory for CAD files and BOM.

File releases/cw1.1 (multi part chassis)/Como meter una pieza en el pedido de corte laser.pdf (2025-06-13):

www.u-motorsport.com | 1

# Como guardar .dxf para corte laser

## Tabla de contenido

1.La pieza es plana.

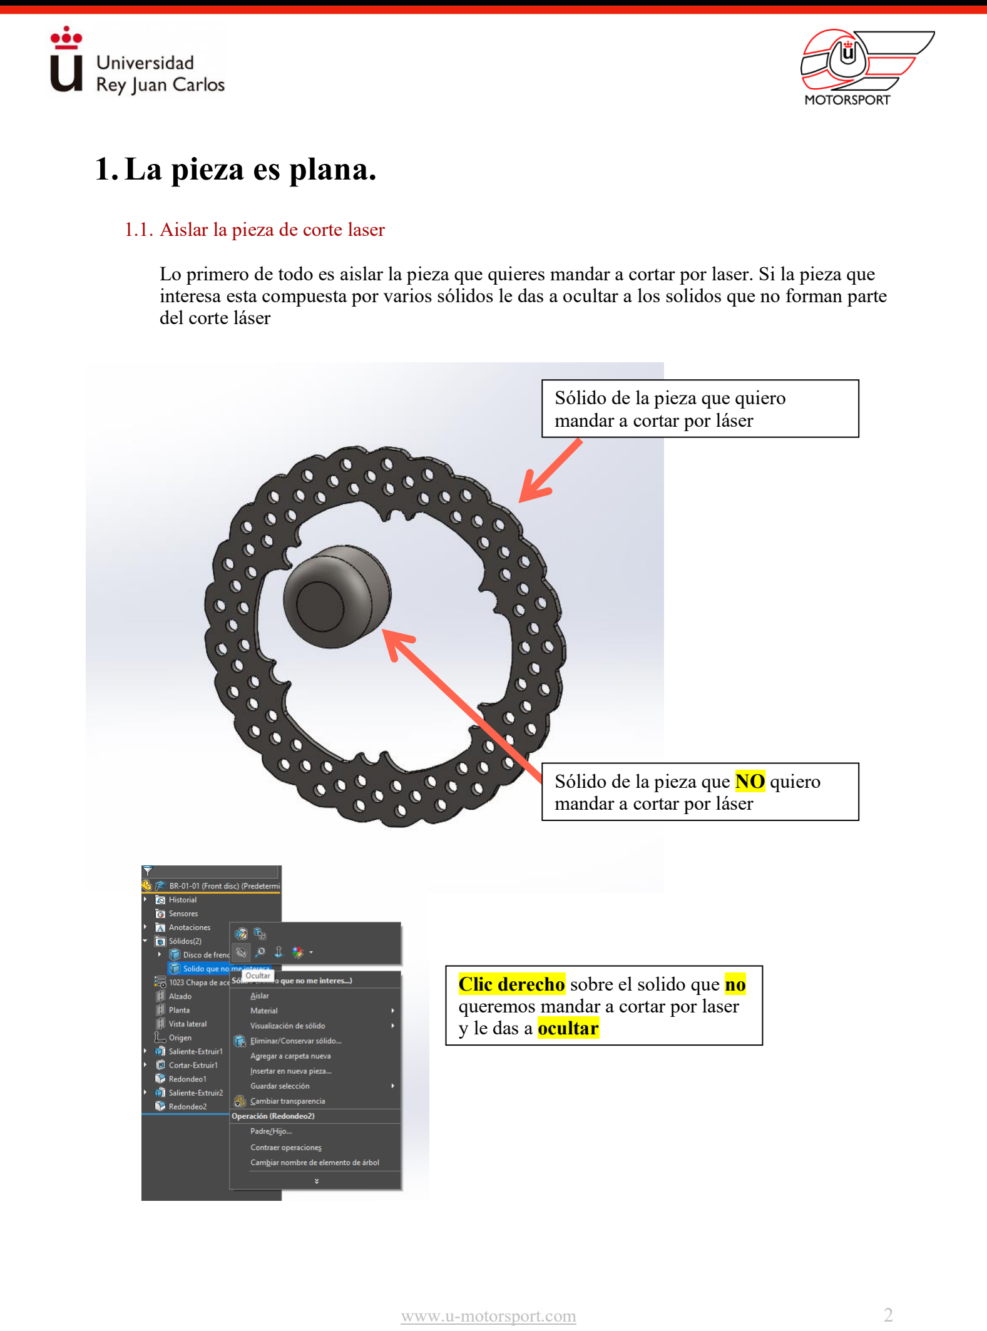
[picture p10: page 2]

1.1. Aislar la pieza de corte laser

Lo primero de todo es aislar la pieza que quieres mandar a cortar por laser. Si la pieza que interesa esta compuesta por varios sólidos le das a ocultar a los solidos que no forman parte del corte láser

Sólido de la pieza que quiero mandar a cortar por láser

Sólido de la pieza que NO quiero mandar a cortar por láser

Clic derecho sobre el solido que no queremos mandar a cortar por laser y le das a ocultar

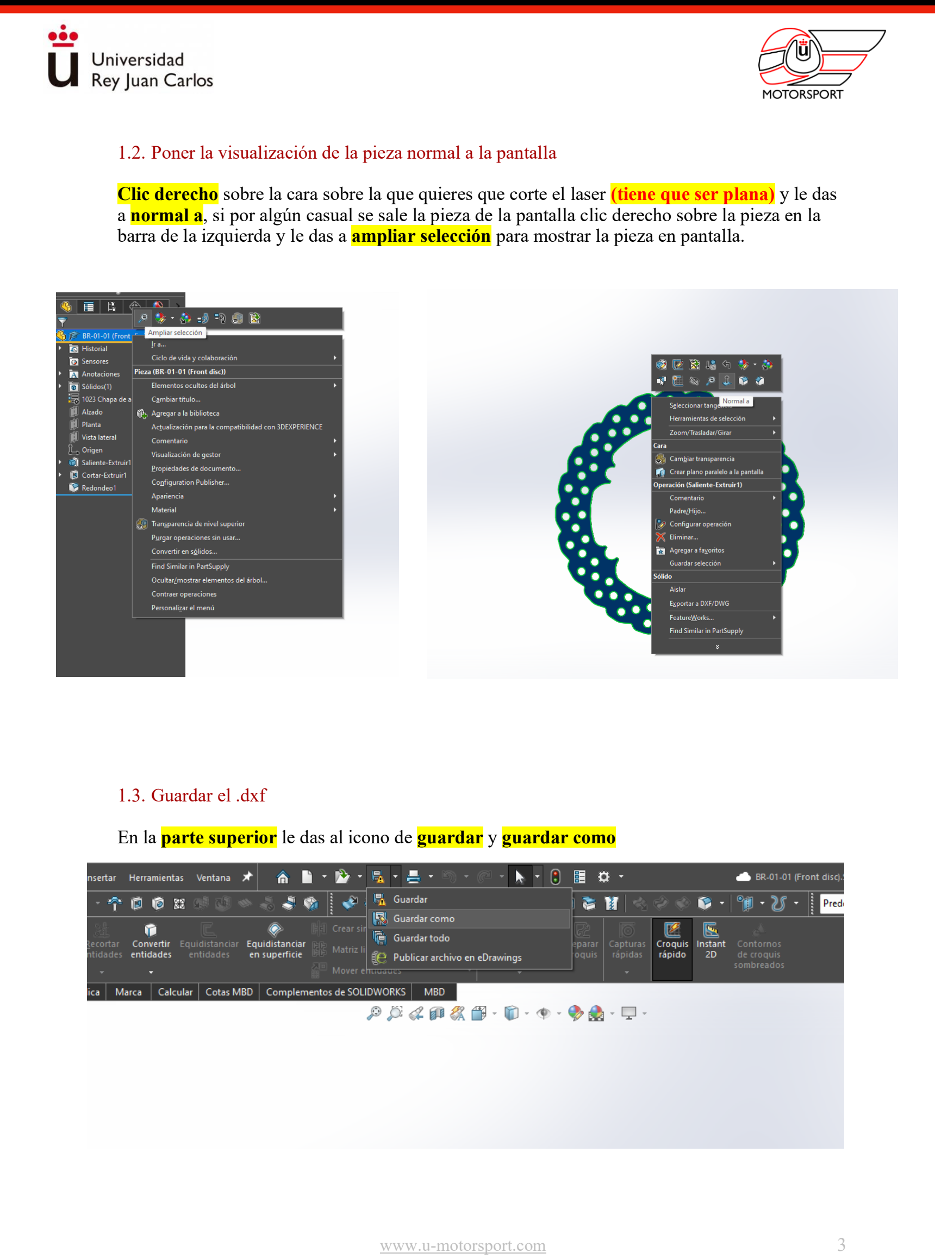
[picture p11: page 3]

1.2. Poner la visualización de la pieza normal a la pantalla

Clic derecho sobre la cara sobre la que quieres que corte el laser (tiene que ser plana) y le das a normal a, si por algún casual se sale la pieza de la pantalla clic derecho sobre la pieza en la barra de la izquierda y le das a ampliar selección para mostrar la pieza en pantalla.

1.3. Guardar el .dxf

En la parte superior le das al icono de guardar y guardar como

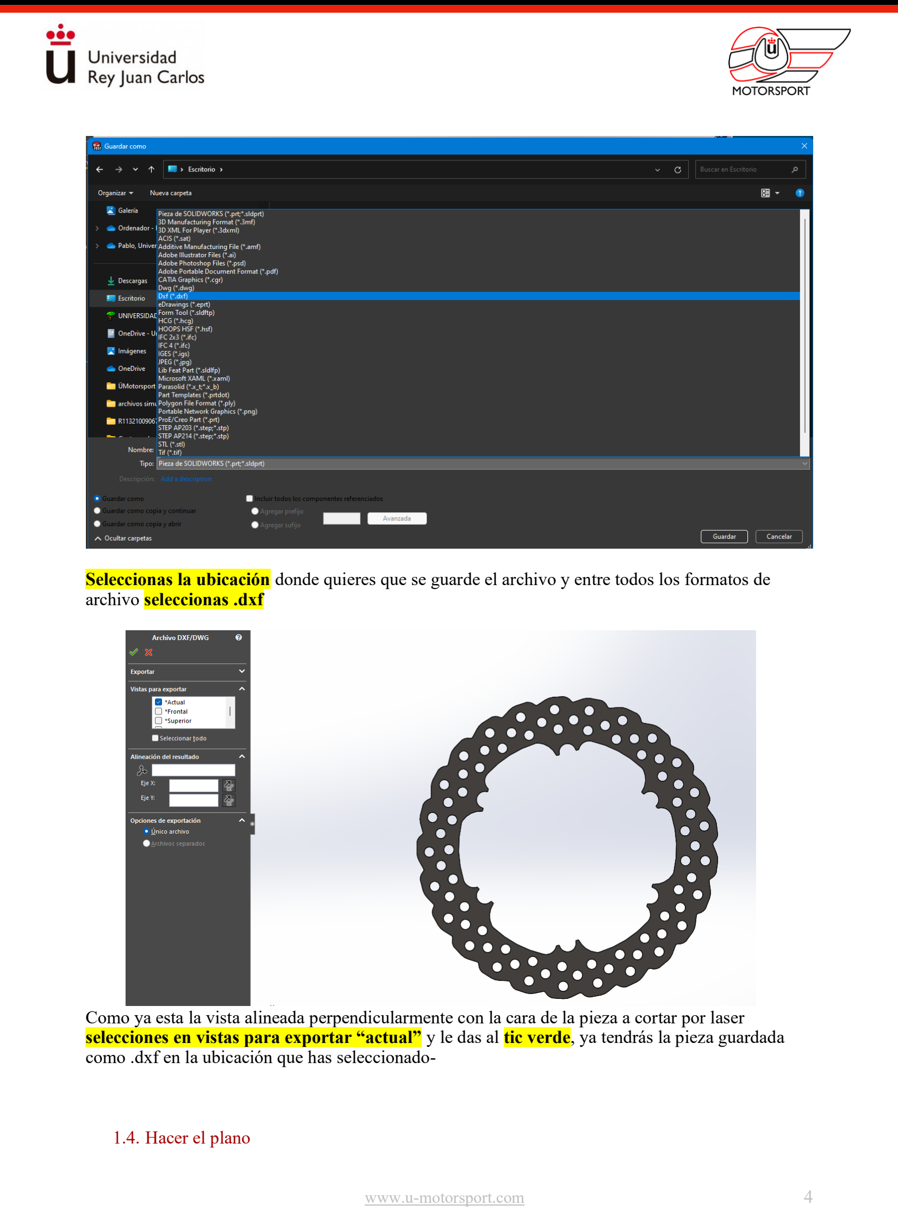
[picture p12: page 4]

Seleccionas la ubicación donde quieres que se guarde el archivo y entre todos los formatos de archivo seleccionas .dxf

Como ya esta la vista alineada perpendicularmente con la cara de la pieza a cortar por laser selecciones en vistas para exportar “actual” y le das al tic verde, ya tendrás la pieza guardada como .dxf en la ubicación que has seleccionado-

1.4. Hacer el plano

Seguir la clase de planos (https://www.youtube.com/watch?v=MBJ9cNJXfwo) para hacer los planos y tener en cuenta que no es lo mismo un plano para la competición que para fabricar la pieza, en el sentido de que muchas veces como el corte laser es “barato” pedimos repuestos de sobra. Tened en cuenta eso y aumentad la cantidad de piezas en el plano solo para el plano de corte laser, el plano para la competición se deja igual.

1.5. Guardar el .step de la pieza

Aunque la pieza sea plana guardar el archivo .step de la pieza

1.6. Subir todo a la carpeta compartida.

He creado una carpeta donde subir todo lo de corte laser EN PDF (IMPORTANTE QUE SEA EN PDF SI NO LA EMPRESA CUANDO LO ABRA ESTARÁ EL PLANO EN BLANCO)

Debes de haber subido:
- .dxf de la pieza
- Plano en PDF de la pieza (revisar que tenga cosas dentro, que no esté vacío)
- .step de la pieza
1.7. Actualizar el Excel

En la carpeta hay un Excel compartido en el que apuntar el nombre de la pieza (entero) , el espesor y el material.

## SI NO SE ACTUALIZA EL EXCEL ESA PIEZA NO SE ACABARÁ FABRICANDO

## 2.La pieza no es plana (tiene doblado de chapa)

2.1. Aislar la pieza (mirar el apartado 1.1 de pieza plana)
2.2. Desplegar la pieza.

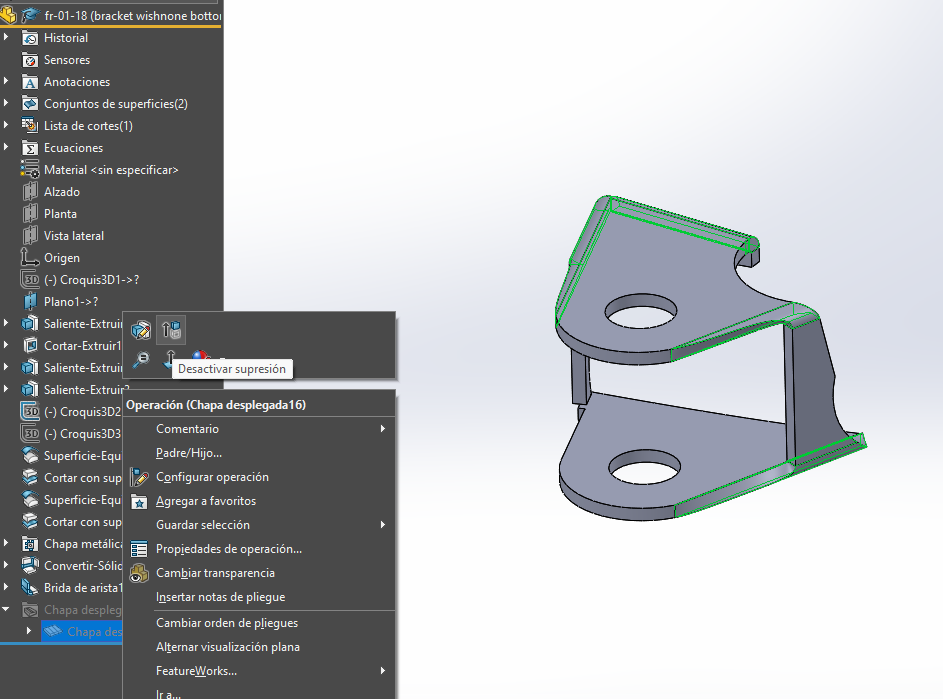
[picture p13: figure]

Con el paso 1 completo en la barra de operaciones bajas hasta la operación de “chapa desplegada” y le das clic derecho y desactivar supresión, la pieza debería desplegarse en plano, si no habrá algún error con las operaciones de chapa metálica, revísalas.

2.3. Poner la visualización de la pieza normal a la pantalla (mirar el apartado 1.2 de pieza plana)

2.4. Guardar el dxf

Se sigue lo mismo que en pieza plana con la siguiente particularidad

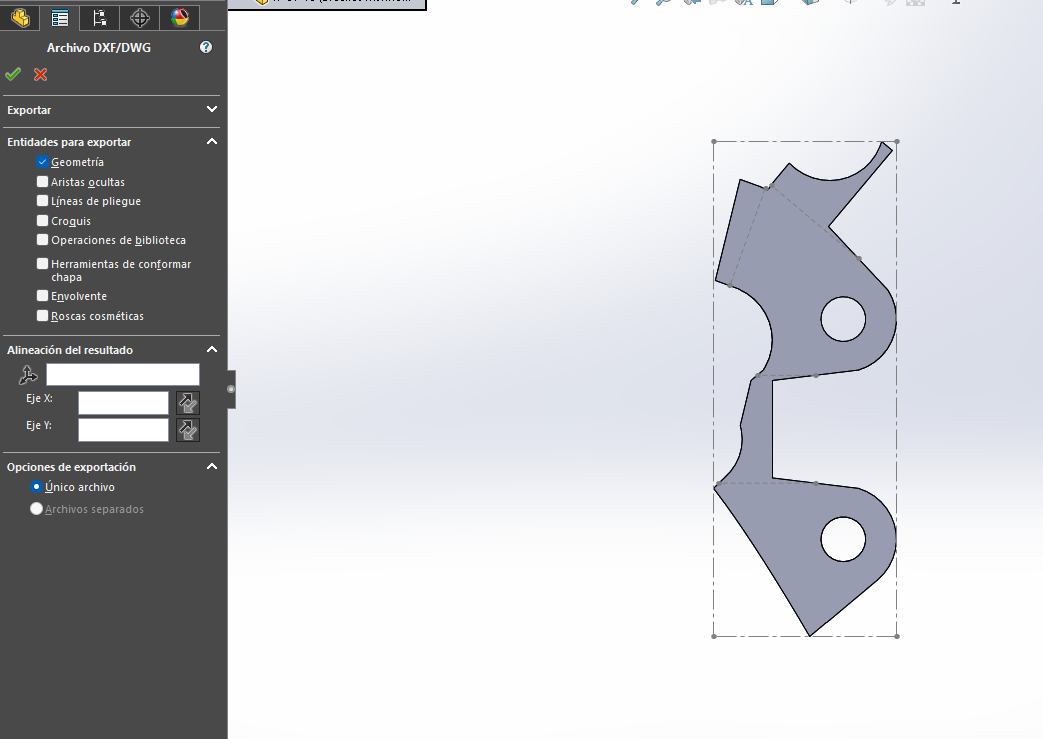
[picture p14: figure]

NOTA: Si no te aparecen esas opciones, guarda la pieza como dxf teniéndola aplanada (flatten) antes.

Al darle a guardar como aparecerá lo siguiente, tendrás que guardar dos archivos .DXF , uno con la opción de geometría activa y otro con la opción de geometría y líneas de pliegue activa. Nombrar el archivo sin líneas de pliegue por ejemplo: FR-01-18 (Bracket wishbone bottom left) sin líneas de pliegue y el archivo con líneas de pliegue FR-01-18 (Bracket wishbone bottom left) con líneas de pliegue

2.5. Hacer el plano

Para el caso de una pieza doblada el plano no es el mismo que para una pieza plana ya que hay que incluir los grados de doblado y hacia donde es el doblado. Para eso tendrás que hacer el plano normal y el plano para fabricación.

Le das al icono de arriba a la derecha para que se vuelva a plegar la pieza y sigues las instrucciones del video de como hacer planos para abrir el plano y seleccionar la

Arrastrar de la derecha una vista isométrica para que la persona que va a doblar la pieza se haga una idea de como tiene que quedar y arrastras también la de chapa desplegada , pones ambas en alámbrico, ajustas la escala y rellenas los campos del plano , importante en QTY como se dijo antes pedir alguna de mas (en doblado ya el precio se incrementa un poco asi que no nos volvamos locos pidiendo tropecientas pletinas de suspen si realmente no son necesarias)

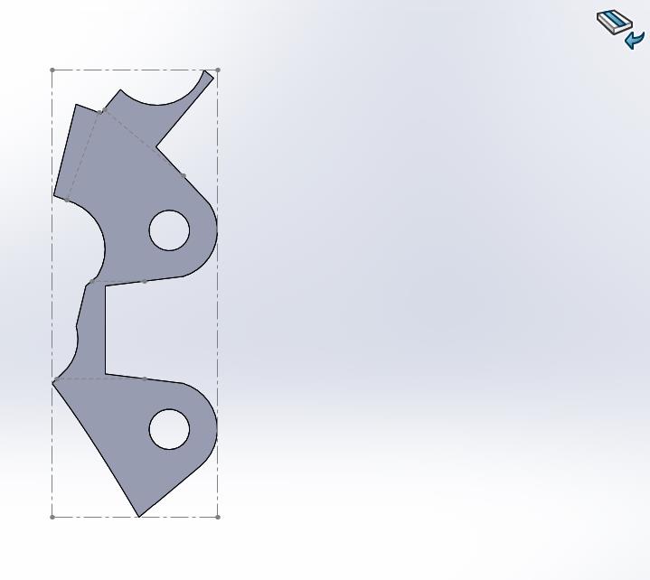
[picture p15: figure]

Si tienes problemas para conseguir que aparezca una vista de la pieza aplanada y otra con la pieza doblada, asgúrate de que el modelo .sldprt tiene la pieza doblada tal y como es, (suprimir flat flatten), pones la vista isométrica normal, y para añadir la vista aplanada, pones una vista front o top lo que sea, y luego haces click en la vista, propiedades, y le das click a “(A) Flat pattern”

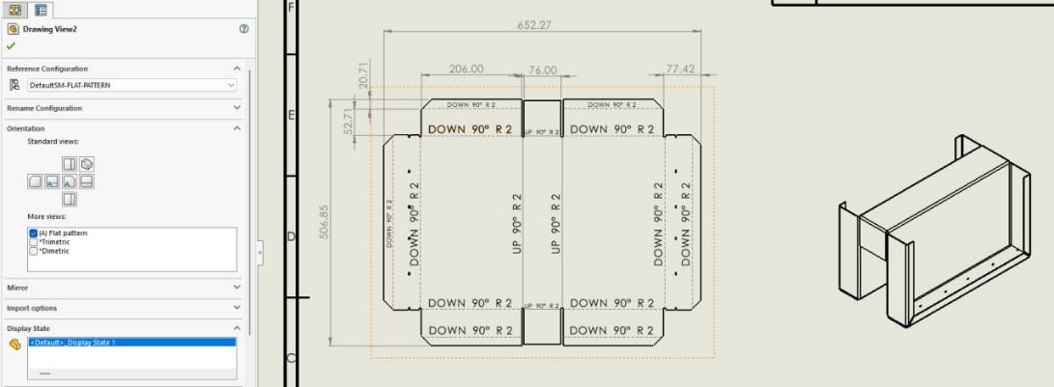
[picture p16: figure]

2.6. Subir los archivos a la carpeta

Como antes pero con la peculiaridad de que tienes que subir:
- .DXF sin líneas de pliegue
- .DXF con líneas de pliegue
- Plano en PDF de fabricación (el que se explica en el punto 2.5)

- .step de la pieza
2.7. Actualizar el Excel

## SI NO SE ACTUALIZA EL EXCEL ESA PIEZA NO SE ACABARÁ FABRICANDO

3.Ejemplo de plano doblado en corte laser.

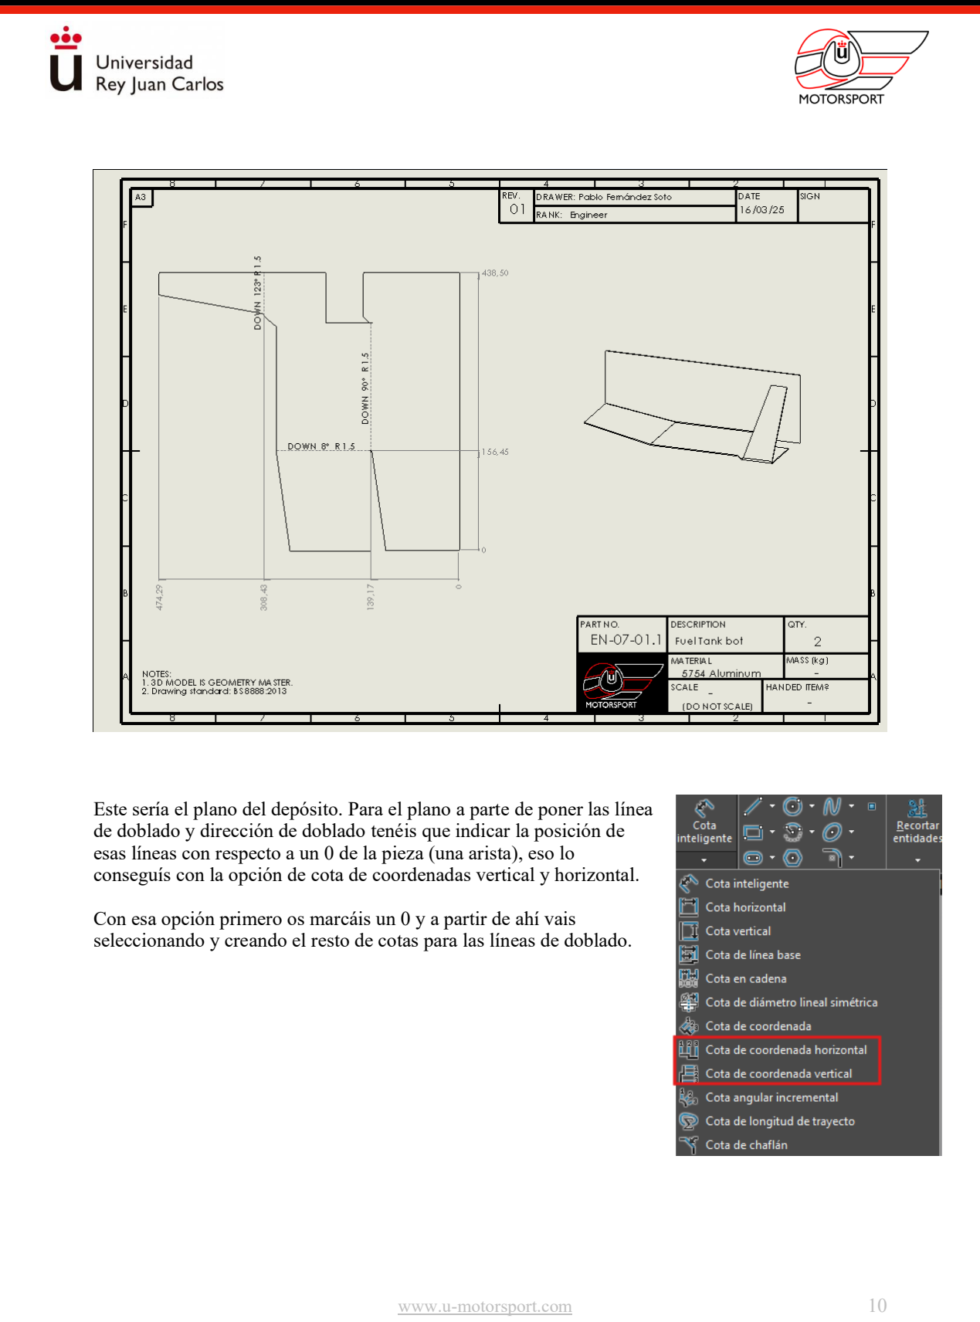
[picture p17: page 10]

Este sería el plano del depósito. Para el plano a parte de poner las línea de doblado y dirección de doblado tenéis que indicar la posición de esas líneas con respecto a un 0 de la pieza (una arista), eso lo conseguís con la opción de cota de coordenadas vertical y horizontal.

Con esa opción primero os marcáis un 0 y a partir de ahí vais seleccionando y creando el resto de cotas para las líneas de doblado.

## 4.Errores comunes y piezas que no valen para corte

laser.

4.1. | Las piezas para corte laser tienen que tener un espesor constante | no por ello no pueden
| presentar dobleces como se ha visto en el punto 2

Este es el ejemplo perfecto de una pieza que no valdría para corte laser o que habría que modificar para que si valiera, si os fijáis la pieza tiene un espesor principal y luego salen dos orejas que son de un espesor mucho menor , si se sacara el dxf de esa pieza si saldrían las orejas , pero cuando nos llegara la pieza nos llegaría con las orejas en el espesor gordo de la pieza y no valdría.

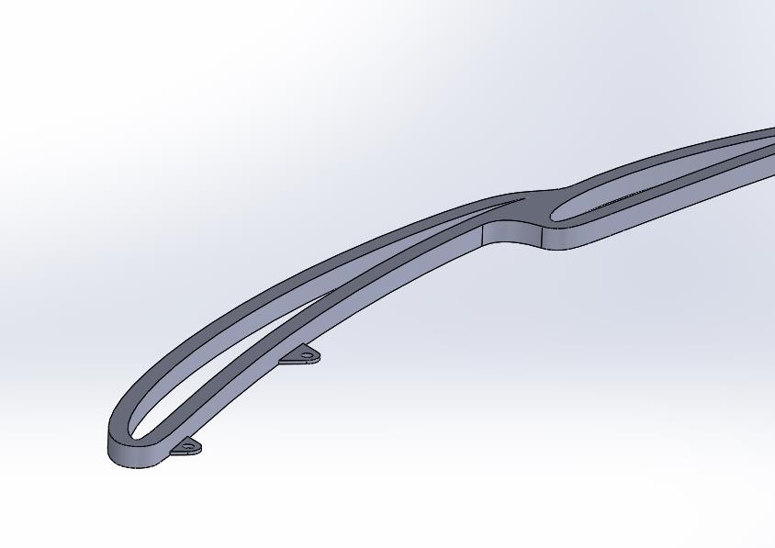
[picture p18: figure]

4.2. Los agujeros en las piezas tienen que ser perpendiculares a la superficie que vayamos a cortar.

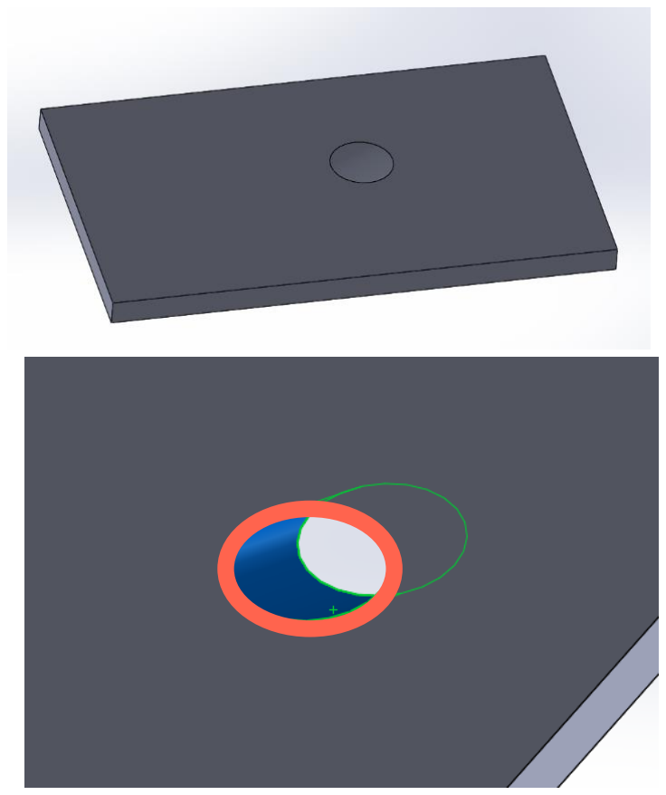
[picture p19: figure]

De primeras esta pieza inventada podría ser un candidato perfecto para corte laser pero si nos fijamos mas detenidamente en el agujero es completamente oblicuo a la superficie (es una exageración). Por lo tanto cuando sacáramos el DXF y mandáramos a cortar la pieza solo nos cortaría la arista roja y por lo tanto el agujero quedaría perpendicular. Si por algún casual necesitamos ese agujero por diseño con ese ángulo esa pieza no valdría y habría que buscar otra forma de hacerla o cambiar el diseño.

4.3. El plano se ha subido en .PDF pero al abrirlo está vacío.

El año pasado algún plano le llegó a la empresa y cuando fueron a abrirlos los planos resulta que no tenían nada dentro, para eso volver a guardar el plano

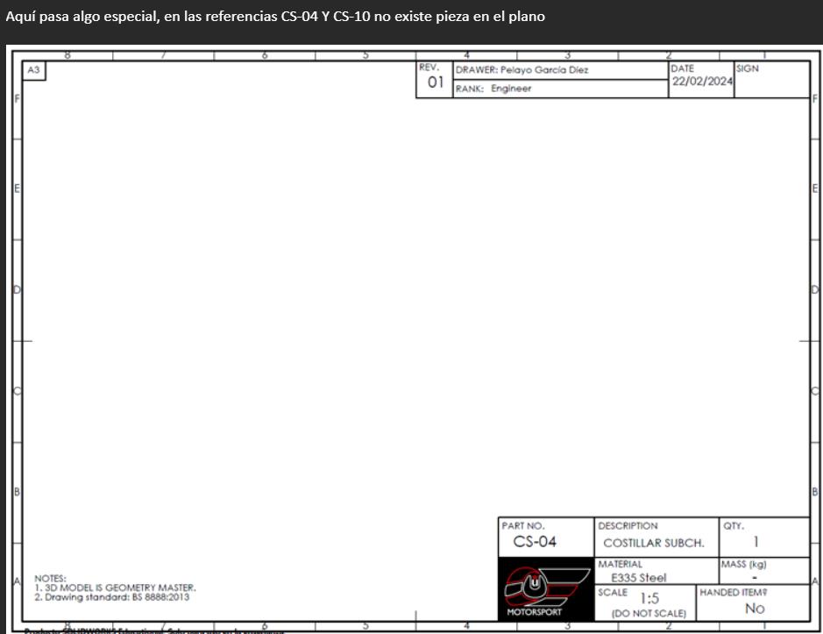
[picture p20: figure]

Captura de un correo de la empresa de corte laser en la que nos dijeron que les enviamos planos vacíos, ridículo absoluto.

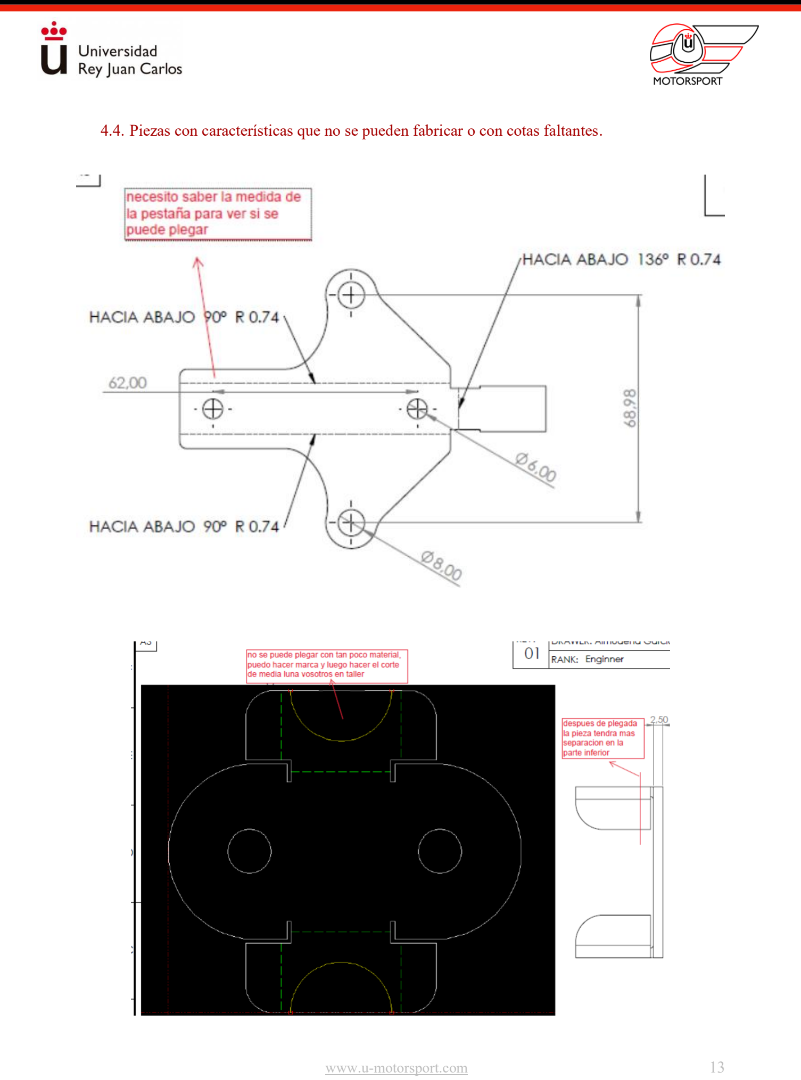
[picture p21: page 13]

4.4. Piezas con características que no se pueden fabricar o con cotas faltantes.

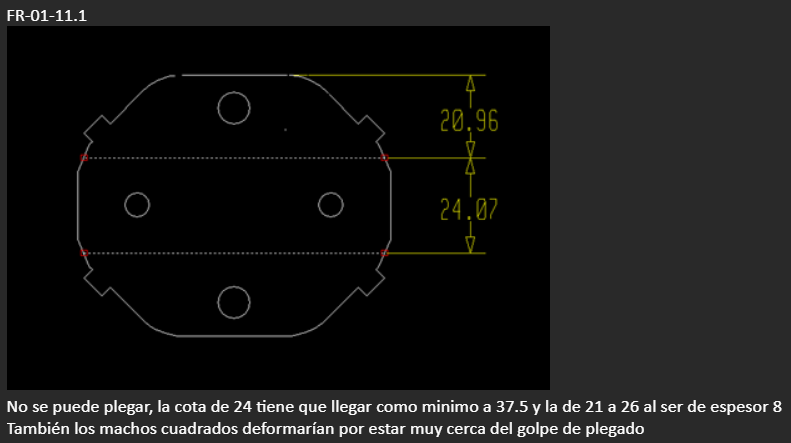
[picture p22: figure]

www.u

-motorsport.com (http://www.u-motorsport.com/) | 14

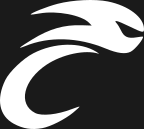
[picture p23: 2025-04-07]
assets/isotype_white_bg_grey.png

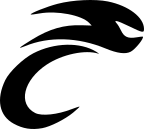
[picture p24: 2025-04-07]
assets/isotype_black_bg_white.png

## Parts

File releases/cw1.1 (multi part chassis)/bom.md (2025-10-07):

# Bill of Materials (BOM) - CW1.1

## Complete EUC Manufacturing Cost

| Component | Price (€) |
|---|---|
| Chassis (laser cut + bent) | 60 |
| VESC Electronics (Little FOCer) | 350 |
| Battery (purchased pre-made) | 700 |
| BMS (Jiabaida) | 52 |
| Motor + Rim | 200 |
| Tire | 50 |
| Assembly labor (30h × 15€/h) | 450 |
| Exterior cover | 50 |
| **TOTAL** | **1,912** |

## Battery Sub-Components (If Self-Manufactured)

| Subcomponent | Price (€) |
|---|---|
| 40× Molicel INR21700-P42A cells (3.85€/cell) | 154 |
| Nickel-copper busbar connections (custom) | 34 |
| Fish paper insulation | 10 |
| Kapton tape | 5 |
| Silicone power cable with crimped connector | 15 |
| Plastic separators | 10 |
| Labor cost (15€/h × 20h) | 300 |
| **TOTAL** | **528** |

## Cost Summary

- **With purchased battery**: 1,912€
- **With self-manufactured battery** (excluding all labor): 990€
- **Total parts only** (no labor, self-made battery): 690€

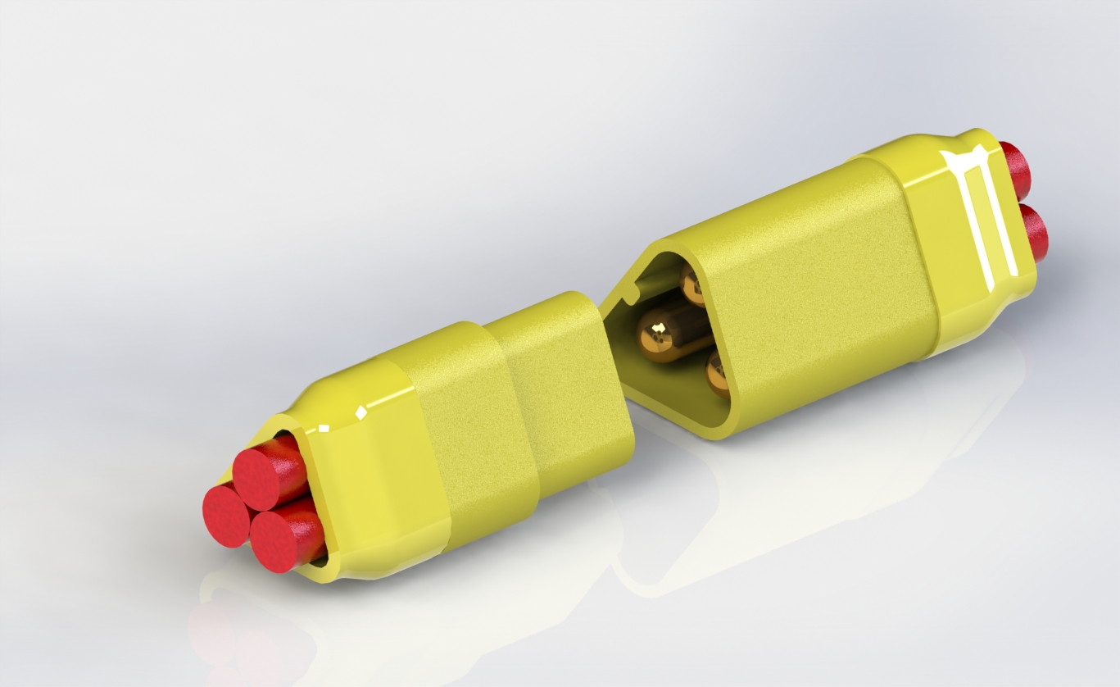
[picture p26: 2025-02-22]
cad/parts/mt60 connector/MT60 Connectors.JPG

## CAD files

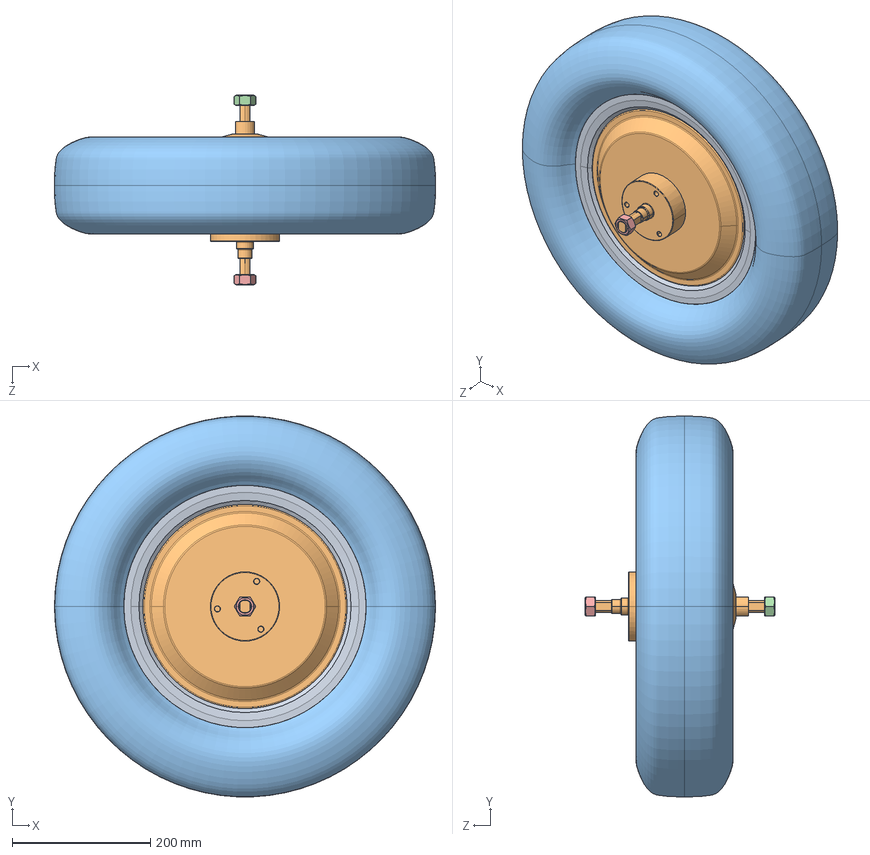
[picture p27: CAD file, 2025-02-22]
releases/cw0.x/cw0.1/cad/wheel.sldasm
550.4 x 549.9 x 275.0 mm
14in QS273 6kW Scooter.stp[2]
14in QS273 6kW Scooter.stp[3]
14in QS273 6kW Scooter.stp[5]
14in QS273 6kW Scooter.stp[6]
14in QS273 6kW Scooter.stp[7]

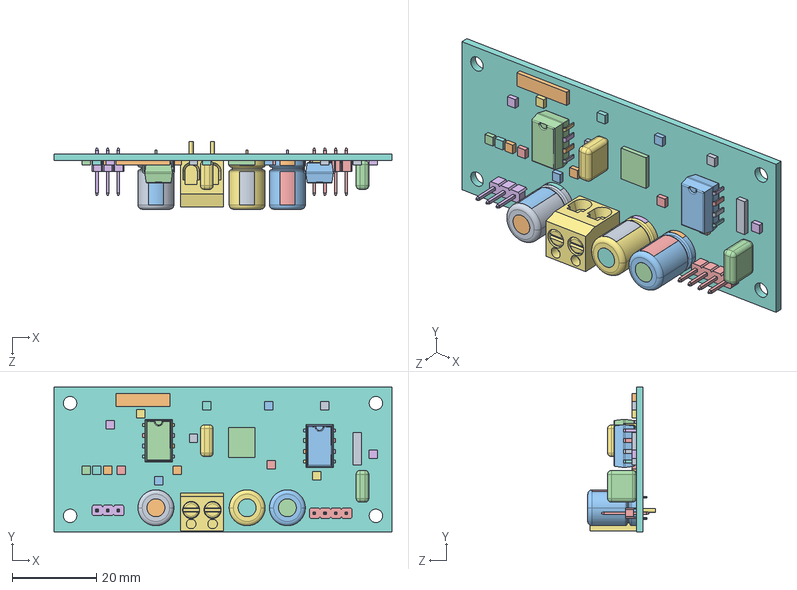
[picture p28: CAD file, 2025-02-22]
releases/cw0.x/cw0.2/cad/servo pcb model/servo control.SLDASM
80.0 x 34.3 x 16.0 mm
CAPPRD500W45D850H1150P001.stp
CAPPRD500W45D850H1150P004.stp
CAPPRD500W45D850H1150P005.stp
CAPPRD500W45D850H1150P002.stp
CAPPRD500W45D850H1150P003.stp
CAPPRD500W45D850H1150P.stp
CAPPRD500W45D850H1150P006.stp
CAPPRD500W45D850H1150P007.stp
CAPPRD500W45D850H1150P008.stp
CAPPRD500W45D850H1150P009.stp
CAPPRD500W45D850H1150P010.stp
CAPPRD500W45D850H1150P011.stp
CAPPRD500W45D850H1150P012.stp
CAPPRD500W45D850H1150P013.stp
CAPPRD500W45D850H1150P014.stp
CAPPRD500W45D850H1150P015.stp
CAPPRD500W45D850H1150P016.stp
CAPPRD500W45D850H1150P017.stp
CAPRR500W50L750T300H680P001.stp
CAPRR500W50L750T300H680P002.stp
CAPRR500W50L750T300H680P.stp
CAPRR500W50L750T300H680P003.stp
CAPRR500W50L750T300H680P004.stp
CAPRR500W50L750T300H680P005.stp
Component_1.stp
Component_2.stp
DIP762W45P254L1015H533Q8P008.stp
DIP762W45P254L1015H533Q8P001.stp
DIP762W45P254L1015H533Q8P006.stp
DIP762W45P254L1015H533Q8P007.stp
DIP762W45P254L1015H533Q8P003.stp
DIP762W45P254L1015H533Q8P004.stp
DIP762W45P254L1015H533Q8P005.stp
DIP762W45P254L1015H533Q8P002.stp
DIP762W45P254L1015H533Q8P.stp
DIP762W45P254L1015H533Q8P009.stp
DIP762W45P254L1015H533Q8P010.stp
DIP762W45P254L1015H533Q8P011.stp
DIP762W45P254L1015H533Q8P012.stp
DIP762W45P254L1015H533Q8P013.stp
DIP762W45P254L1015H533Q8P014.stp
DIP762W45P254L1015H533Q8P015.stp
DIP762W45P254L1015H533Q8P016.stp
DIP762W45P254L1015H533Q8P017.stp
1.stp
1001.stp
Component_3.stp
Component_004.stp
Component_005.stp
Component_006.stp
Component_007.stp
Component_4.stp
Component_008.stp
Component_009.stp
Component_010.stp
Component_011.stp
Component_012.stp
Component_013.stp
Component_014.stp
Component_015.stp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

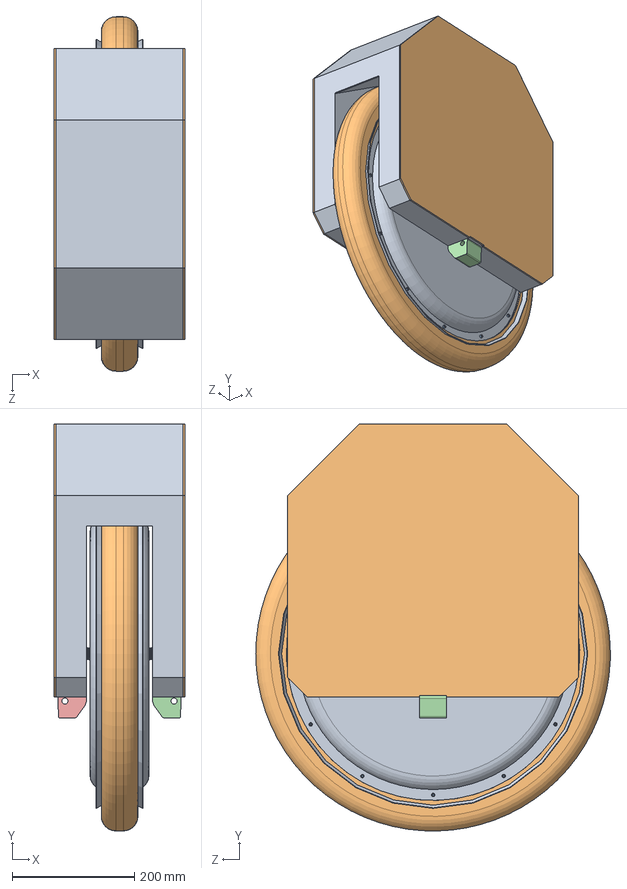
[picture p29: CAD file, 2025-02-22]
releases/cw0.x/cw0.4 (easy steel weld 2)/cad/euc0.4.SLDASM
214.0 x 665.6 x 579.8 mm
motor
tyre
socket head cap screw_ai x 24
pedal hanger1
pedal hanger2
Chassis^euc0.3
Lid x 2
Battery
Battery2
Battery3
Battery4

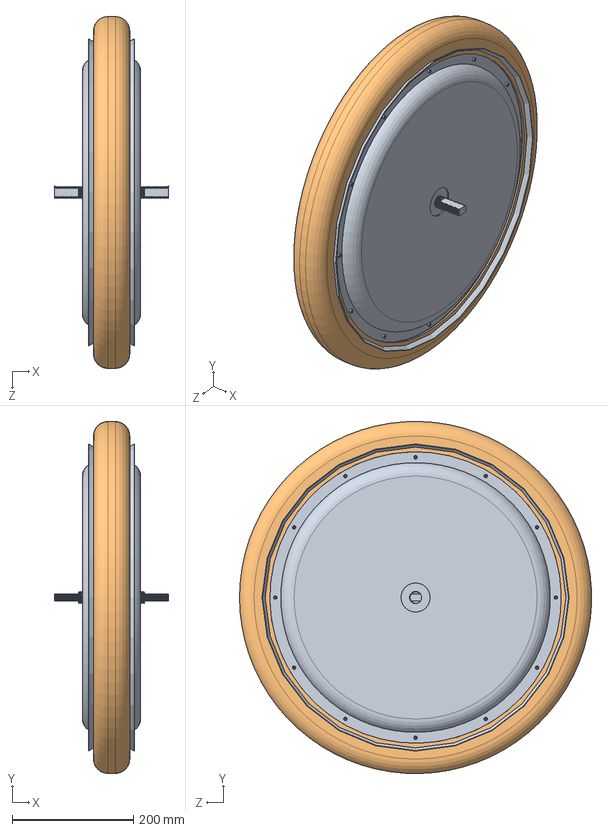
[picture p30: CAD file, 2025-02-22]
releases/cw0.x/cw0.4 (easy steel weld 2)/cad/wheel/wheel.SLDASM
188.0 x 579.9 x 579.8 mm
motor
tyre
socket head cap screw_ai x 24

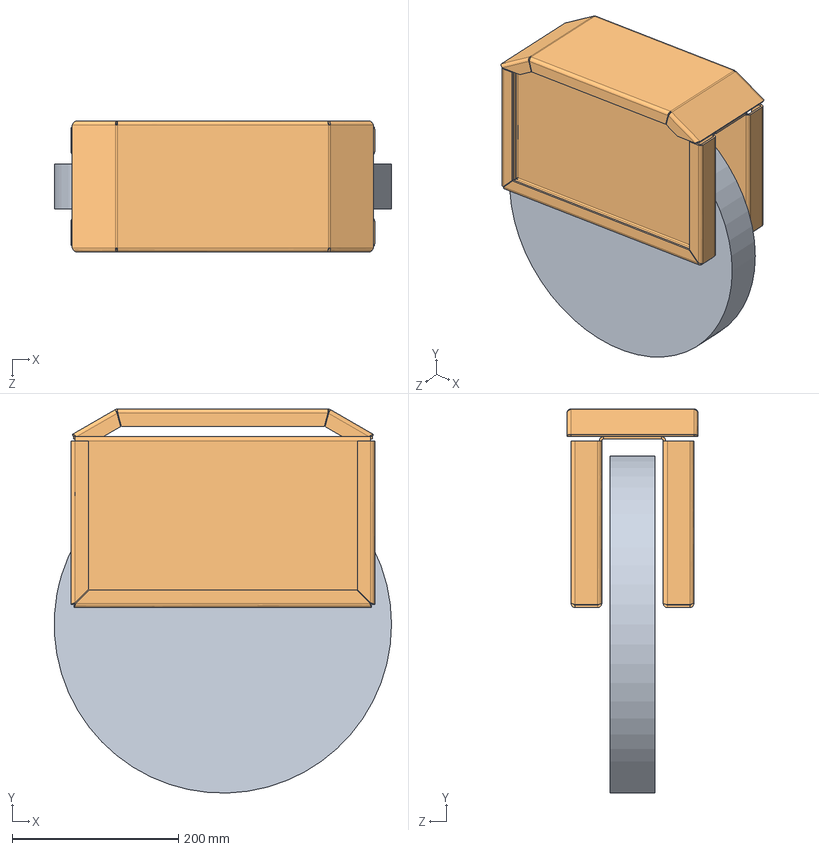
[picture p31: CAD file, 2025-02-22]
releases/cw0.x/cw0.8 (laser cut aluminum)/cad/euc0.8.SLDASM
406.0 x 462.6 x 158.0 mm
tire^euc0.8
chassis_square

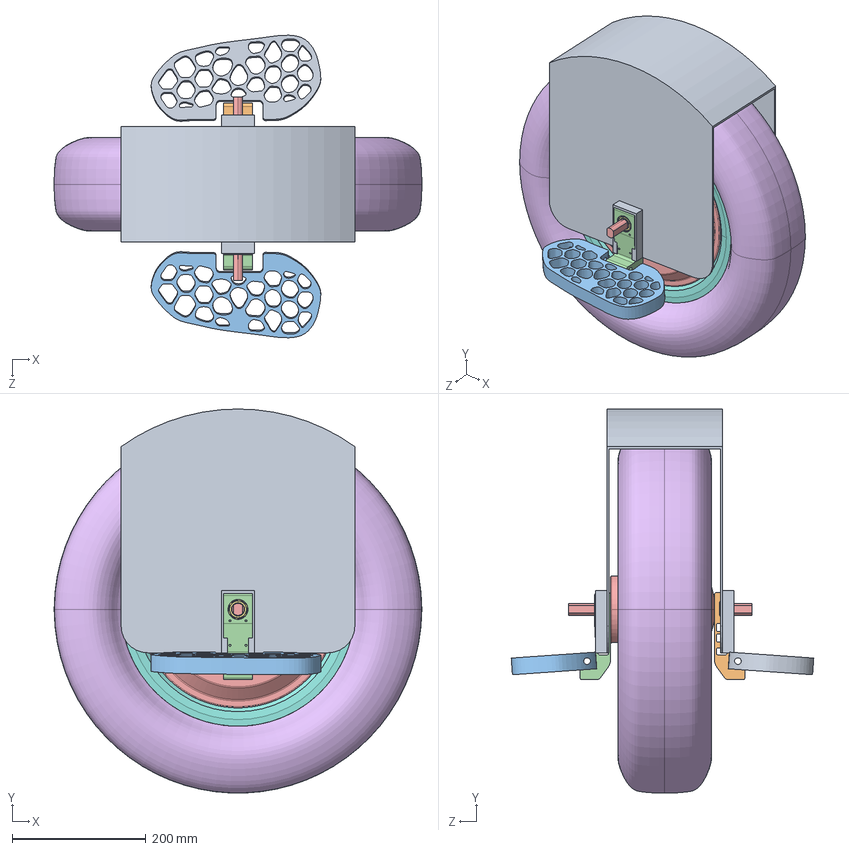
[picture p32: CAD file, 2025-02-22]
cad/ultimate_euc.SLDASM
550.4 x 575.0 x 453.0 mm
nylonove_pedals
pedal holder solid
Mirrornylonove_pedals
Mirrorpedal holder solid
14in QS273 6kW Scooter.stp[3]
14in QS273 6kW Scooter.stp[5]
14in QS273 6kW Scooter.stp[6] x 2
14in QS273 6kW Scooter.stp[2]2
Chassis

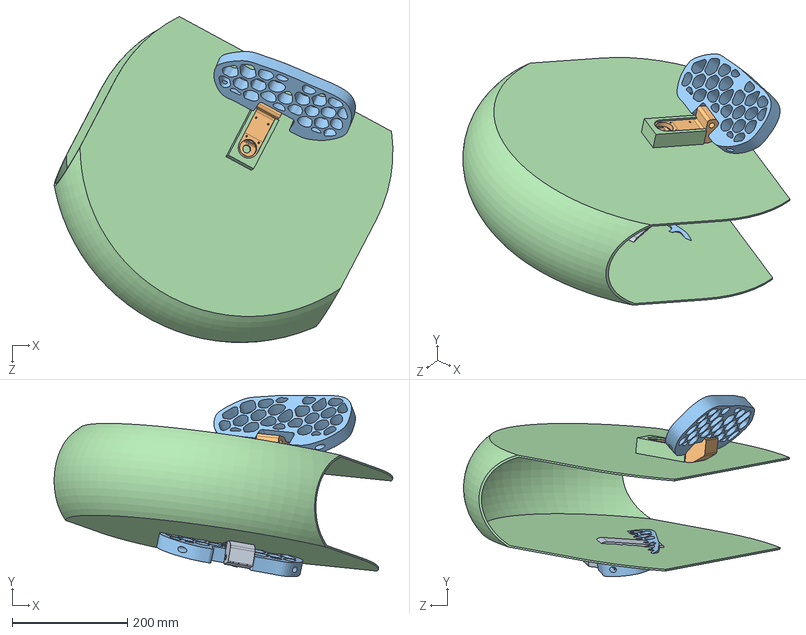
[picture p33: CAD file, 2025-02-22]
releases/cw0.x/cw0.1/cad/euc0.1.SLDASM
587.0 x 314.2 x 565.0 mm
pedal holder solid
pedal holder solid lh
nylonove_pedals x 2
chassis

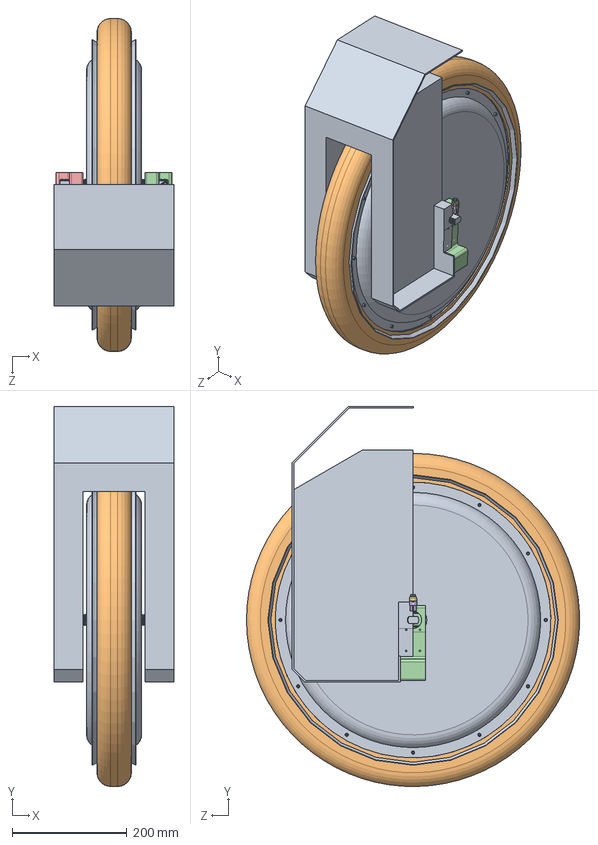
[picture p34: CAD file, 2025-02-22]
releases/cw0.x/cw0.3 (easy steel weld 1)/cad/euc0.3.SLDASM
208.3 x 661.5 x 579.8 mm
motor
tyre
socket head cap screw_ai x 24
pedal hanger1
pedal hanger2
Internal chassis^Chassis_euc0.3

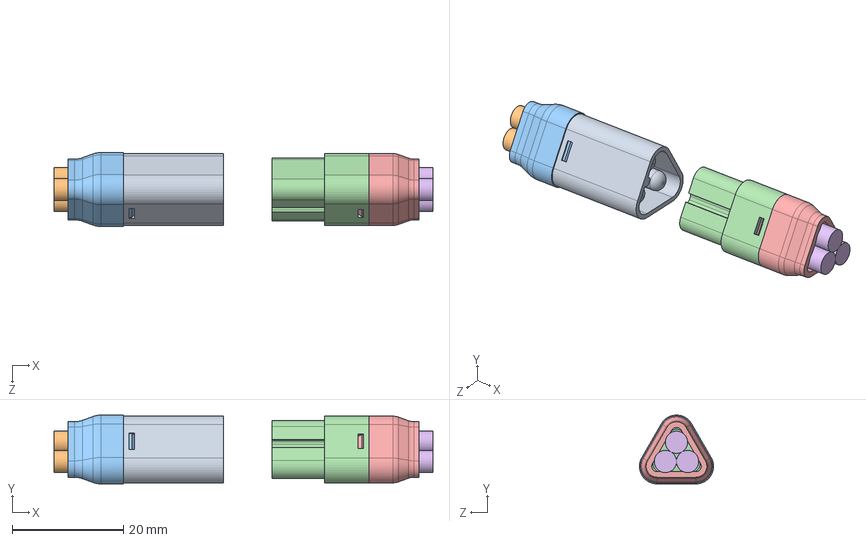
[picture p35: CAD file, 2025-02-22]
cad/parts/mt60 connector/MT60.SLDASM
68.2 x 12.4 x 13.3 mm
Copy of Папа^mt60 male
Copy of Провода^mt60 male
Copy of Колпчек^mt60 male
Copy of Мама^mt60 female
Copy of Колпачек 2^mt60 female
Copy of Деталь11^mt60 female

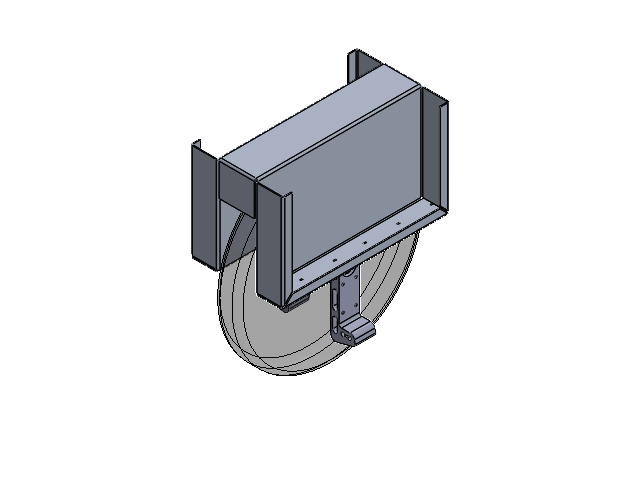
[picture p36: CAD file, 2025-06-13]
releases/cw1.0 (improved, helmet lid)/cad/ueuc10.SLDASM
pedal_hanger_inmotion x 2
chassis
wheel

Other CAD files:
cad/parts/mt60 connector/mt60 male.sldasm
cad/Pedal subassembly.sldasm
releases/cw0.x/cw0.2/cad/chassis/Chassis.sldasm
releases/cw0.x/cw0.3 (easy steel weld 1)/cad/chassis/Chassis.sldasm
cad/parts/mt60 connector/mt60 female.sldasm
releases/cw0.x/cw0.2/cad/wheel/wheel.SLDASM
releases/cw0.x/cw0.3 (easy steel weld 1)/cad/wheel/wheel.SLDASM
releases/cw0.x/cw0.7 actual 16in wheel/cad/mt60 fem.sldasm
cad/MirrorPedal subassembly.sldasm
cad/Mirrornylonove_pedals.SLDPRT
cad/Mirrorpedal holder solid.sldprt
cad/chassis.SLDPRT
cad/euc0.2.SLDASM
cad/hexagon_sketch.SLDPRT
cad/parts/10in_hub_wheel.step
cad/parts/14in QS273 6kW Scooter.SLDPRT
cad/parts/14in QS273 6kW Scooter.stp
cad/parts/nylonove_pedals.STEP
cad/parts/pedal holder.STEP
cad/parts/pedal holder.step.SLDPRT
cad/parts/servo pcb model/servo control.SLDASM
cad/parts/servo pcb model/servo control.SLDPRT
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

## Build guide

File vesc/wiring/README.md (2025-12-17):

# Wiring

Use for pinouts, harness drawings, connector part numbers, and photos. Keep voltage/current ratings and wire gauges alongside the drawings.

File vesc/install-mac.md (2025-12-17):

# Install VESC Tool on macOS (tested 2025-03)

Downloaded file: `~/Downloads/vesc_tool_mac.zip` (contains `VESC Tool.dmg`).

Steps
1) Unzip if needed:
   ```bash
   cd ~/Downloads
   unzip -n vesc_tool_mac.zip
   ```
2) Mount the DMG:
   ```bash
   hdiutil attach "VESC Tool.dmg"
   # mounts as /Volumes/VESC\ Tool\ 1
   ```
3) Copy to user Applications (no sudo needed):
   ```bash
   mkdir -p ~/Applications
   cp -R "/Volumes/VESC Tool 1/VESC Tool.app" ~/Applications/
   ```
4) Clear quarantine/lock flags and ensure writable:
   ```bash
   xattr -dr com.apple.quarantine ~/Applications/VESC\ Tool.app
   chflags -R nouchg ~/Applications/VESC\ Tool.app
   chmod -R u+rwX ~/Applications/VESC\ Tool.app
   ```
5) Eject the DMG:
   ```bash
   hdiutil detach "/Volumes/VESC Tool 1"
   ```
6) Launch (and pass Gatekeeper prompt):
   ```bash
   open ~/Applications/VESC\ Tool.app
   ```

Optional: move to system `/Applications` via Finder drag-and-drop (enter your Mac password) after clearing quarantine. Then launch with:
```bash
open /Applications/VESC\ Tool.app
```

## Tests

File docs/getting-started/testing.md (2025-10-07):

# Testing

This page will contain test procedures to validate the CYBERWHEEL design.

## Test Categories

### Structural Tests
- Impact resistance
- Vibration tolerance
- Weatherproofing validation

### Electrical Tests
- Battery performance under load
- BMS functionality
- Motor controller validation
- Emergency cutoff behavior

### Safety Tests
- Cutout prevention
- Emergency response
- Thermal limits
- Voltage protection

### Performance Tests
- Speed and acceleration
- Range testing
- Hill climbing
- Temperature management

## Test Procedures

*Coming soon - detailed test procedures for each category*

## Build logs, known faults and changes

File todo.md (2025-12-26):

user vs model parameters, difference? why they get added as user

check dimensions

Hacer el diseño en fusion 360
Diseñar y fabricar la tapa superior
Diseñar soporte para la batería y la electrónica

base datos con contactos, excel o algo. y de donde ha salido.
power ui? excel vale

validar coste y precios, prototipo y encuesta, contactos proveedores

create an about page in cyberwheel docs

configure pid with balance app (refloat doesn't work)
create video about the project

save vesc config in the release, or in stuff, at least

put the euc in fusion and add 3d printed designs to hold batteries and electronics in place.

comprar: aislante mosfet electronica

note all required connectors and stuff to buy

- buy Shrink wrap (transparent? inspect all cells, visible from sides)
    - perimeter (2170 cells): 4*21.7 + 4 * 70 = 366.8mm
    - width of flat roll before contraction > 183.4mm to fit

# Issues
- Can the chassis be done as a single laser-cut bent piece? What about rivetting several ones?
    - Airplane wings use sealants that cure along with rivets. Consider it
- Insurance?
    - Personal liability insurance for PMV should be enough.

# Questions
- Should I ground the chassis for signals? Or isolate it from everything? (It will not be connected to any battery terminal)
- Is it possible to calculate the slope based on the inclination and motor current draw?
    - Assuming static wind relative to ground, high current draw at low speed must be high slope, high speed 0 draw is no inclination or slightly negative etc. Might allow leveling lights that compensate acceleration and don't blind. Also raise more than usual when accelerating.
- Why not the battery on top? Electronics Top-Front and Battery Top-Behind. Test adding weight on top.
- REGEN Efficiency?
- Connect - of battery with chassis or isolate it?
- How does Mitch calculate the PID parameters in the code? float, int with precision, interrupts and global variables...
- Battery at the top makes it unstable or ok? If ok electronics at bottom and battery at top. If battery at bottom, experiment with parallel batteries to conform to the non-rectangular shape
- Weight at the bottom for stability and low center of mass? I'm not sure if it matters. (Similar to trailer oscillations? Top heavy wheel could oscillate, but bottom heavy just has inertia in the wheel, and can roll easily). With weight at the top of the wheel I might have more leverage to prevent a fall. Experiment.
- **Why does death wobble happen? Truly understand the mechanics.**
- Can the slope of the path be inferred from the motor behavior? f(acceleration, speed, current)
- Is there a way to provide active thermal management to the battery and electronics, for such a vehicle? Peltier?
- Use the same mosfets of the EUC for charging the battery, so we skip most of the charging circuitry? (When doing regen the motor generates high voltage AC power, which is rectified to the battery. That's basically the same as charging from the wall). Must be safe.

# Tests
- Try battery on top and electronics at the sides. It's waaay simpler that way. See if it's problematic the high center of mass.
- Measure and graph wobble speed vs center of mass. Ask mechanics techaers.

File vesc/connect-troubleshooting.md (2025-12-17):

# VESC USB connection checks (Mac)

Symptoms: VESC Tool “Could not autoconnect” and no `/dev/tty.usb*` port.

Checklist
- Power: ESC must be powered from pack or bench supply (current-limited). LEDs on.
- Cable: use a known data cable (USB-C to USB-A + adapter often more reliable than some C-to-C charge-only cables).
- Port listing: in Terminal, `ls /dev/tty.usb*`. If nothing, macOS is not seeing the USB-serial device.
- Replug: unplug USB, wait 5s, replug. Try a different Mac port.
- Driver: if the board uses CH340, install the WCH macOS driver; CP210x/FTDI usually work with built-in drivers.
- System Info: `system_profiler SPUSBDataType | head -n 120` should show the device under USB if detected (even if no tty appears).
- VESC Tool: Connection tab → select the `/dev/tty.usb*` port manually → Connect (instead of Autoconnect).
- Last resort: try another cable/adapter or another computer to confirm the ESC’s USB interface is alive.

Little FOCer V3.1 (CP2102) specific
- The Little FOCer V3.1 uses a Silicon Labs CP2102 USB-UART; macOS often needs the CP210x VCP driver.
- Download: https://www.silabs.com/developers/usb-to-uart-bridge-vcp-drivers (choose macOS, ARM vs Intel accordingly), install, then reboot.
- After install, port should appear as `/dev/tty.SLAB_USBtoUART` (or `/dev/cu.SLAB_USBtoUART`). Select it manually in VESC Tool.
- macOS approval: During install, you may need to approve a driver extension. In System Settings → Privacy & Security, scroll to “Driver Extensions” and enable `CP210xVCPDriver (com.silabs.cp210x)`. If prompted with “system software from developer Silicon Laboratories Inc. was blocked,” click Allow, then reboot.
- If the port still doesn’t show after reboot: replug USB with the ESC powered, try a different cable/port, then check `ls /dev/tty.SLAB* /dev/cu.SLAB*`. If no match, use `system_profiler SPUSBDataType` to see if macOS sees the device at all. If nothing shows, suspect the cable/port/board.

Cable sensitivity (real-world note)
- The Little FOCer’s USB-C port can be picky about USB 2.0 D+/D– quality/fit. In testing, one high-quality C-to-C cable enumerated reliably as `Serial STM32 /dev/tty.usbmodemXXXX`; another “good” cable worked on iPhone/Mac but would not enumerate the LF. If you see the port only with a specific cable/orientation, mark that cable as the known-good for VESC.
- On one LF, USB only worked in a specific plug orientation (1 of 4 cable/port combos). Likely cause: one side of the LF USB-C receptacle has weak/dirty/bent contacts. Workaround: mark the known-good orientation, avoid movement, and consider leaving a short, snug USB-C pigtail plugged in permanently to reduce wear.

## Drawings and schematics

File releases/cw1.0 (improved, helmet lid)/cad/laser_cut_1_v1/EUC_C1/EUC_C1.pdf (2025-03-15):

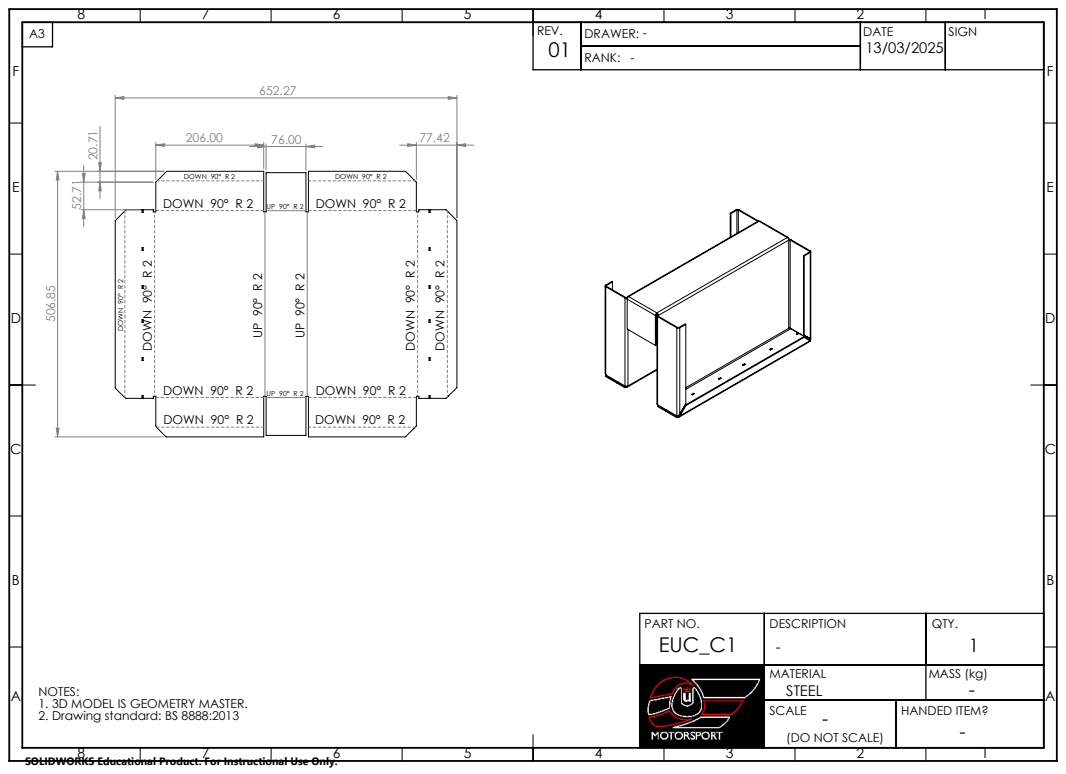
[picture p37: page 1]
DOWN 90° R 2; DOWN 90° R 2 UP 90° R 2; NOTES:; - 1. 3D MODEL IS GEOMETRY MASTER.

A3 | 652.27 | REV. 01 | DRAWER: - | DATE | SIGN

PART NO. EUC_C1 | DESCRIPTION - | QTY. 1

MATERIAL STEEL | MASS (kg)

2. Drawing standard: BS 8888:2013

SCALE | HANDED ITEM? - - (DO NOT SCALE)

SOLIDWORKS Educational Product. For Instructional Use Only.

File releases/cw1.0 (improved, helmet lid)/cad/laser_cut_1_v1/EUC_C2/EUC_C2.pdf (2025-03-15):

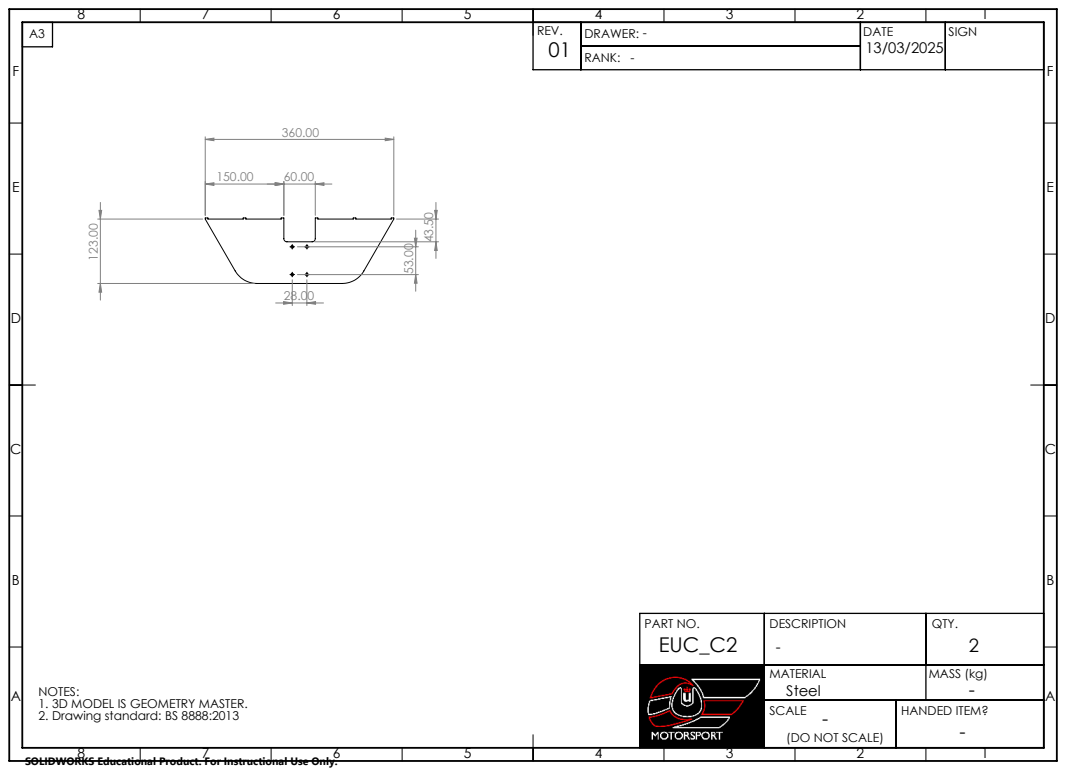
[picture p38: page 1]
NOTES:; - 1. 3D MODEL IS GEOMETRY MASTER.

A3 | 360.00 | REV. 01 | DRAWER: - | DATE | SIGN

PART NO. EUC_C2 | DESCRIPTION - | QTY. 2

MATERIAL Steel | MASS (kg)

2. Drawing standard: BS 8888:2013

SCALE | HANDED ITEM? - - (DO NOT SCALE)

SOLIDWORKS Educational Product. For Instructional Use Only.

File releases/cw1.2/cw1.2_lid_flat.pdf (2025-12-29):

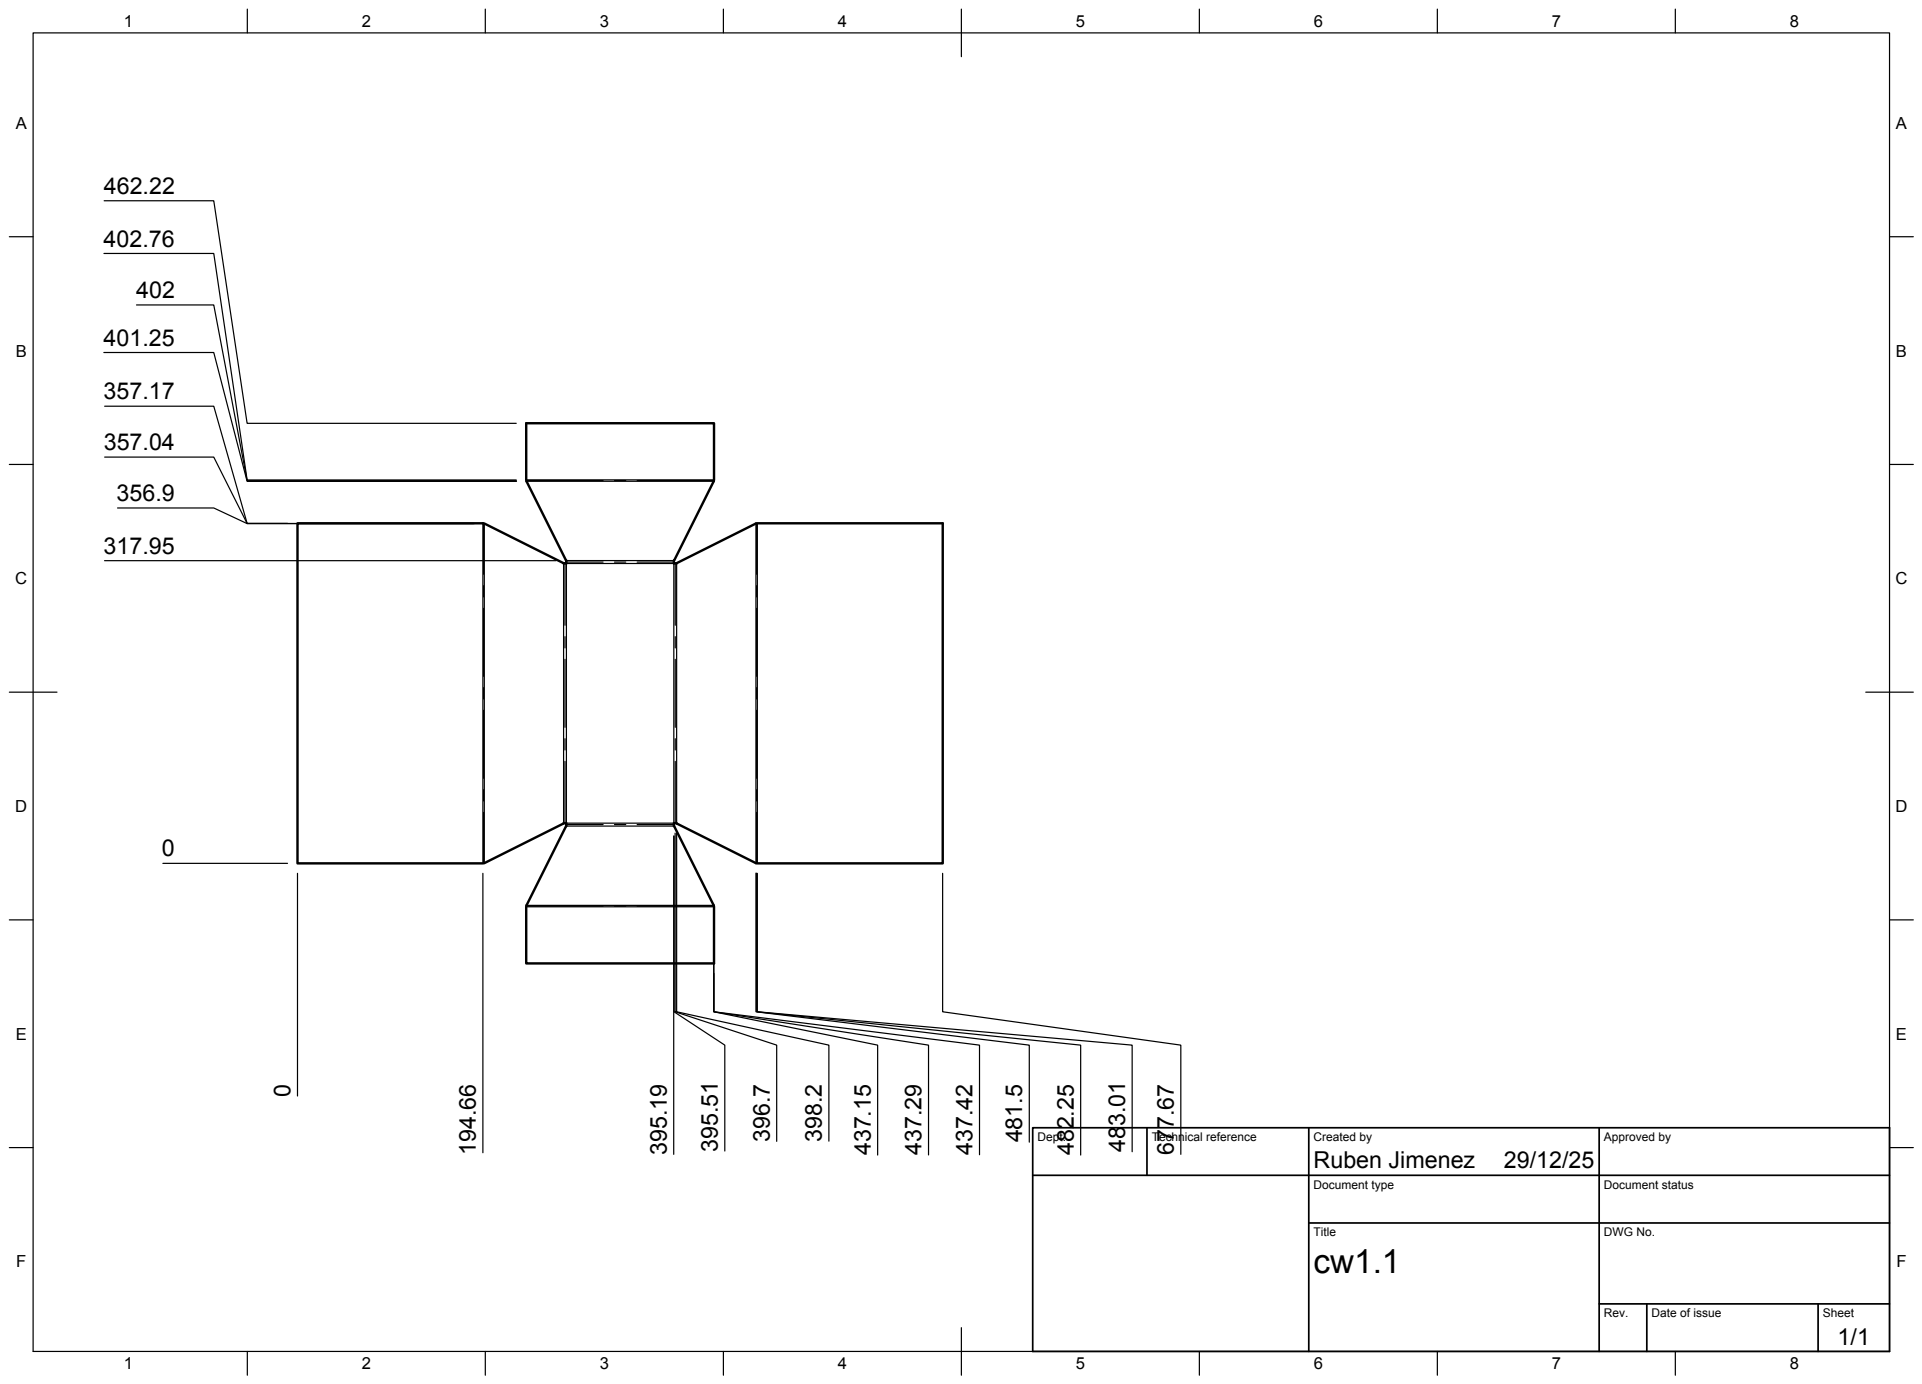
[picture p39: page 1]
Title; DWG No.; Rev.; Date of issue; Sheet

Dept. | Technical reference | Created by Ruben Jimenez 29/12/25 | Approved by

Document type | Document status

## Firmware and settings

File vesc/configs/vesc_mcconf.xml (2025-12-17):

<?xml version="1.0" encoding="UTF-8"?>
<MCConfiguration>
    <pwm_mode>1</pwm_mode>
    <comm_mode>0</comm_mode>
    <motor_type>2</motor_type>
    <sensor_mode>0</sensor_mode>
    <l_current_max>60</l_current_max>
    <l_current_min>-60</l_current_min>
    <l_in_current_max>99</l_in_current_max>
    <l_in_current_min>-60</l_in_current_min>
    <l_in_current_map_start>1</l_in_current_map_start>
    <l_in_current_map_filter>0.005</l_in_current_map_filter>
    <l_abs_current_max>150</l_abs_current_max>
    <l_min_erpm>-100000</l_min_erpm>
    <l_max_erpm>100000</l_max_erpm>
    <l_erpm_start>0.8</l_erpm_start>
    <l_max_erpm_fbrake>300</l_max_erpm_fbrake>
    <l_max_erpm_fbrake_cc>1500</l_max_erpm_fbrake_cc>
    <l_min_vin>8</l_min_vin>
    <l_max_vin>57</l_max_vin>
    <l_battery_cut_start>10</l_battery_cut_start>
    <l_battery_cut_end>8</l_battery_cut_end>
    <l_battery_regen_cut_start>1000</l_battery_regen_cut_start>
    <l_battery_regen_cut_end>1100</l_battery_regen_cut_end>
    <l_slow_abs_current>0</l_slow_abs_current>
    <l_temp_fet_start>85</l_temp_fet_start>
    <l_temp_fet_end>100</l_temp_fet_end>
    <l_temp_motor_start>85</l_temp_motor_start>
    <l_temp_motor_end>100</l_temp_motor_end>
    <l_temp_accel_dec>0.15</l_temp_accel_dec>
    <l_min_duty>0.005</l_min_duty>
    <l_max_duty>0.95</l_max_duty>
    <l_watt_max>1.5e+06</l_watt_max>
    <l_watt_min>-1.5e+06</l_watt_min>
    <l_current_max_scale>1</l_current_max_scale>
    <l_current_min_scale>1</l_current_min_scale>
    <l_duty_start>1</l_duty_start>
    <sl_min_erpm>150</sl_min_erpm>
    <sl_min_erpm_cycle_int_limit>1100</sl_min_erpm_cycle_int_limit>
    <sl_max_fullbreak_current_dir_change>10</sl_max_fullbreak_current_dir_change>
    <sl_cycle_int_limit>62</sl_cycle_int_limit>
    <sl_phase_advance_at_br>0.8</sl_phase_advance_at_br>
    <sl_cycle_int_rpm_br>80000</sl_cycle_int_rpm_br>
    <sl_bemf_coupling_k>600</sl_bemf_coupling_k>
    <hall_table__0>-1</hall_table__0>
    <hall_table__1>1</hall_table__1>
    <hall_table__2>3</hall_table__2>
    <hall_table__3>2</hall_table__3>
    <hall_table__4>5</hall_table__4>
    <hall_table__5>6</hall_table__5>
    <hall_table__6>4</hall_table__6>
    <hall_table__7>-1</hall_table__7>
    <hall_sl_erpm>2000</hall_sl_erpm>
    <foc_current_kp>0.0123</foc_current_kp>
    <foc_current_ki>11.85</foc_current_ki>
    <foc_f_zv>30000</foc_f_zv>
    <foc_dt_us>0.12</foc_dt_us>
    <foc_encoder_inverted>0</foc_encoder_inverted>
    <foc_encoder_offset>180</foc_encoder_offset>
    <foc_encoder_ratio>7</foc_encoder_ratio>
    <foc_sensor_mode>0</foc_sensor_mode>
    <foc_pll_kp>2000</foc_pll_kp>
    <foc_pll_ki>30000</foc_pll_ki>
    <foc_motor_l>1.227e-05</foc_motor_l>
    <foc_motor_ld_lq_diff>3.77e-06</foc_motor_ld_lq_diff>
    <foc_motor_r>0.0118</foc_motor_r>
    <foc_motor_flux_linkage>0.004014</foc_motor_flux_linkage>
    <foc_observer_gain>6.206e+07</foc_observer_gain>
    <foc_observer_gain_slow>0.05</foc_observer_gain_slow>
    <foc_observer_offset>-1</foc_observer_offset>
    <foc_duty_dowmramp_kp>50</foc_duty_dowmramp_kp>
    <foc_duty_dowmramp_ki>1000</foc_duty_dowmramp_ki>
    <foc_start_curr_dec>1</foc_start_curr_dec>
    <foc_start_curr_dec_rpm>2500</foc_start_curr_dec_rpm>
    <foc_openloop_rpm>1500</foc_openloop_rpm>
    <foc_openloop_rpm_low>0</foc_openloop_rpm_low>
    <foc_d_gain_scale_start>0.9</foc_d_gain_scale_start>
    <foc_d_gain_scale_max_mod>0.2</foc_d_gain_scale_max_mod>
    <foc_sl_openloop_hyst>0.1</foc_sl_openloop_hyst>
    <foc_sl_openloop_time_lock>0</foc_sl_openloop_time_lock>
    <foc_sl_openloop_time_ramp>0.1</foc_sl_openloop_time_ramp>
    <foc_sl_openloop_time>0.05</foc_sl_openloop_time>
    <foc_sl_openloop_boost_q>0</foc_sl_openloop_boost_q>
    <foc_sl_openloop_max_q>-1</foc_sl_openloop_max_q>
    <foc_hall_table__0>255</foc_hall_table__0>
    <foc_hall_table__1>255</foc_hall_table__1>
    <foc_hall_table__2>255</foc_hall_table__2>
    <foc_hall_table__3>255</foc_hall_table__3>
    <foc_hall_table__4>255</foc_hall_table__4>
    <foc_hall_table__5>255</foc_hall_table__5>
    <foc_hall_table__6>255</foc_hall_table__6>
    <foc_hall_table__7>255</foc_hall_table__7>
    <foc_hall_interp_erpm>500</foc_hall_interp_erpm>
    <foc_sl_erpm_start>2500</foc_sl_erpm_start>
    <foc_sl_erpm>3500</foc_sl_erpm>
    <foc_control_sample_mode>0</foc_control_sample_mode>
    <foc_current_sample_mode>0</foc_current_sample_mode>
    <foc_sat_comp_mode>2</foc_sat_comp_mode>
    <foc_sat_comp>0</foc_sat_comp>
    <foc_temp_comp>0</foc_temp_comp>
    <foc_temp_comp_base_temp>25</foc_temp_comp_base_temp>
    <foc_current_filter_const>0.1</foc_current_filter_const>
    <foc_cc_decoupling>0</foc_cc_decoupling>
    <foc_observer_type>3</foc_observer_type>
    <foc_hfi_amb_mode>0</foc_hfi_amb_mode>
    <foc_hfi_amb_current>60</foc_hfi_amb_current>
    <foc_hfi_amb_tres>15</foc_hfi_amb_tres>
    <foc_hfi_voltage_start>20</foc_hfi_voltage_start>
    <foc_hfi_voltage_run>4</foc_hfi_voltage_run>
    <foc_hfi_voltage_max>6</foc_hfi_voltage_max>
    <foc_hfi_gain>0.3</foc_hfi_gain>
    <foc_hfi_max_err>0.15</foc_hfi_max_err>
    <foc_hfi_hyst>0</foc_hfi_hyst>
    <foc_sl_erpm_hfi>3000</foc_sl_erpm_hfi>
    <foc_hfi_start_samples>5</foc_hfi_start_samples>
    <foc_hfi_obs_ovr_sec>0.001</foc_hfi_obs_ovr_sec>
    <foc_hfi_samples>1</foc_hfi_samples>
    <foc_offsets_cal_mode>1</foc_offsets_cal_mode>
    <foc_offsets_current__0>2047.39</foc_offsets_current__0>
    <foc_offsets_current__1>2048.29</foc_offsets_current__1>
    <foc_offsets_current__2>2048.89</foc_offsets_current__2>
    <foc_offsets_voltage__0>0.0002</foc_offsets_voltage__0>
    <foc_offsets_voltage__1>0.0006</foc_offsets_voltage__1>
    <foc_offsets_voltage__2>-0.0009</foc_offsets_voltage__2>
    <foc_offsets_voltage_undriven__0>0.0005</foc_offsets_voltage_undriven__0>
    <foc_offsets_voltage_undriven__1>-0.0003</foc_offsets_voltage_undriven__1>
    <foc_offsets_voltage_undriven__2>-0.0002</foc_offsets_voltage_undriven__2>
    <foc_phase_filter_enable>1</foc_phase_filter_enable>
    <foc_phase_filter_disable_fault>1</foc_phase_filter_disable_fault>
    <foc_phase_filter_max_erpm>4000</foc_phase_filter_max_erpm>
    <foc_mtpa_mode>0</foc_mtpa_mode>
    <foc_fw_current_max>0</foc_fw_current_max>
    <foc_fw_duty_start>0.9</foc_fw_duty_start>
    <foc_fw_q_current_factor>0.02</foc_fw_q_current_factor>
    <foc_fw_ramp_time>0.2</foc_fw_ramp_time>
    <foc_speed_soure>0</foc_speed_soure>
    <foc_short_ls_on_zero_duty>0</foc_short_ls_on_zero_duty>
    <foc_overmod_factor>1</foc_overmod_factor>
    <sp_pid_loop_rate>5</sp_pid_loop_rate>
    <s_pid_kp>0.004</s_pid_kp>
    <s_pid_ki>0.004</s_pid_ki>
    <s_pid_kd>0.0001</s_pid_kd>
    <s_pid_kd_filter>0.2</s_pid_kd_filter>
    <s_pid_min_erpm>900</s_pid_min_erpm>
    <s_pid_allow_braking>1</s_pid_allow_braking>
    <s_pid_ramp_erpms_s>25000</s_pid_ramp_erpms_s>
    <s_pid_speed_source>0</s_pid_speed_source>
    <p_pid_kp>0.025</p_pid_kp>
    <p_pid_ki>0</p_pid_ki>
    <p_pid_kd>0</p_pid_kd>
    <p_pid_offset>0</p_pid_offset>
    <p_pid_kd_proc>0.00035</p_pid_kd_proc>
    <p_pid_kd_filter>0.2</p_pid_kd_filter>
    <p_pid_ang_div>1</p_pid_ang_div>
    <p_pid_gain_dec_angle>0</p_pid_gain_dec_angle>
    <cc_startup_boost_duty>0.01</cc_startup_boost_duty>
    <cc_min_current>0.05</cc_min_current>
    <cc_gain>0.0046</cc_gain>
    <cc_ramp_step_max>0.04</cc_ramp_step_max>
    <m_fault_stop_time_ms>500</m_fault_stop_time_ms>
    <m_duty_ramp_step>0.02</m_duty_ramp_step>
    <m_current_backoff_gain>0.5</m_current_backoff_gain>
    <m_encoder_counts>8192</m_encoder_counts>
    <m_encoder_sin_amp>1</m_encoder_sin_amp>
    <m_encoder_cos_amp>1</m_encoder_cos_amp>
    <m_encoder_sin_offset>1.65</m_encoder_sin_offset>
    <m_encoder_cos_offset>1.65</m_encoder_cos_offset>
    <m_encoder_sincos_filter_constant>0.5</m_encoder_sincos_filter_constant>
    <m_encoder_sincos_phase_correction>0</m_encoder_sincos_phase_correction>
    <m_sensor_port_mode>0</m_sensor_port_mode>
    <m_invert_direction>0</m_invert_direction>
    <m_drv8301_oc_mode>0</m_drv8301_oc_mode>
    <m_drv8301_oc_adj>19</m_drv8301_oc_adj>
    <m_bldc_f_sw_min>3000</m_bldc_f_sw_min>
    <m_bldc_f_sw_max>35000</m_bldc_f_sw_max>
    <m_dc_f_sw>25000</m_dc_f_sw>
    <m_ntc_motor_beta>3380</m_ntc_motor_beta>
    <m_out_aux_mode>0</m_out_aux_mode>
    <m_motor_temp_sens_type>0</m_motor_temp_sens_type>
    <m_ptc_motor_coeff>0.61</m_ptc_motor_coeff>
    <m_ntcx_ptcx_res>10000</m_ntcx_ptcx_res>
    <m_ntcx_ptcx_temp_base>25</m_ntcx_ptcx_temp_base>
    <m_hall_extra_samples>3</m_hall_extra_samples>
    <m_batt_filter_const>45</m_batt_filter_const>
    <si_motor_poles>14</si_motor_poles>
    <si_gear_ratio>3</si_gear_ratio>
    <si_wheel_diameter>0.083</si_wheel_diameter>
    <si_battery_type>0</si_battery_type>
    <si_battery_cells>3</si_battery_cells>
    <si_battery_ah>6</si_battery_ah>
    <si_motor_nl_current>1</si_motor_nl_current>
    <motor_brand></motor_brand>
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

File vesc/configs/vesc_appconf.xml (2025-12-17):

<?xml version="1.0" encoding="UTF-8"?>
<APPConfiguration>
    <ConfigVersion>4</ConfigVersion>
    <controller_id>74</controller_id>
    <timeout_msec>1000</timeout_msec>
    <timeout_brake_current>0</timeout_brake_current>
    <can_status_rate_1>50</can_status_rate_1>
    <can_status_rate_2>5</can_status_rate_2>
    <can_status_msgs_r1>0</can_status_msgs_r1>
    <can_status_msgs_r2>0</can_status_msgs_r2>
    <can_baud_rate>2</can_baud_rate>
    <pairing_done>0</pairing_done>
    <permanent_uart_enabled>1</permanent_uart_enabled>
    <shutdown_mode>7</shutdown_mode>
    <can_mode>0</can_mode>
    <uavcan_esc_index>0</uavcan_esc_index>
    <uavcan_raw_mode>0</uavcan_raw_mode>
    <uavcan_raw_rpm_max>50000</uavcan_raw_rpm_max>
    <uavcan_status_current_mode>0</uavcan_status_current_mode>
    <servo_out_enable>0</servo_out_enable>
    <kill_sw_mode>0</kill_sw_mode>
    <app_to_use>3</app_to_use>
    <app_ppm_conf.ctrl_type>0</app_ppm_conf.ctrl_type>
    <app_ppm_conf.pid_max_erpm>15000</app_ppm_conf.pid_max_erpm>
    <app_ppm_conf.hyst>0.15</app_ppm_conf.hyst>
    <app_ppm_conf.pulse_start>1</app_ppm_conf.pulse_start>
    <app_ppm_conf.pulse_end>2</app_ppm_conf.pulse_end>
    <app_ppm_conf.pulse_center>1.5</app_ppm_conf.pulse_center>
    <app_ppm_conf.median_filter>1</app_ppm_conf.median_filter>
    <app_ppm_conf.safe_start>1</app_ppm_conf.safe_start>
    <app_ppm_conf.throttle_exp>0</app_ppm_conf.throttle_exp>
    <app_ppm_conf.throttle_exp_brake>0</app_ppm_conf.throttle_exp_brake>
    <app_ppm_conf.throttle_exp_mode>2</app_ppm_conf.throttle_exp_mode>
    <app_ppm_conf.ramp_time_pos>0.4</app_ppm_conf.ramp_time_pos>
    <app_ppm_conf.ramp_time_neg>0.2</app_ppm_conf.ramp_time_neg>
    <app_ppm_conf.multi_esc>1</app_ppm_conf.multi_esc>
    <app_ppm_conf.tc>0</app_ppm_conf.tc>
    <app_ppm_conf.tc_max_diff>3000</app_ppm_conf.tc_max_diff>
    <app_ppm_conf.max_erpm_for_dir>4000</app_ppm_conf.max_erpm_for_dir>
    <app_ppm_conf.smart_rev_max_duty>0.07</app_ppm_conf.smart_rev_max_duty>
    <app_ppm_conf.smart_rev_ramp_time>3</app_ppm_conf.smart_rev_ramp_time>
    <app_adc_conf.ctrl_type>8</app_adc_conf.ctrl_type>
    <app_adc_conf.hyst>0.05</app_adc_conf.hyst>
    <app_adc_conf.voltage_start>0.6</app_adc_conf.voltage_start>
    <app_adc_conf.voltage_end>2.54</app_adc_conf.voltage_end>
    <app_adc_conf.voltage_min>0</app_adc_conf.voltage_min>
    <app_adc_conf.voltage_max>3.6</app_adc_conf.voltage_max>
    <app_adc_conf.voltage_center>0.6</app_adc_conf.voltage_center>
    <app_adc_conf.voltage2_start>0</app_adc_conf.voltage2_start>
    <app_adc_conf.voltage2_end>2</app_adc_conf.voltage2_end>
    <app_adc_conf.use_filter>1</app_adc_conf.use_filter>
    <app_adc_conf.safe_start>1</app_adc_conf.safe_start>
    <app_adc_conf.buttons>0</app_adc_conf.buttons>
    <app_adc_conf.voltage_inverted>0</app_adc_conf.voltage_inverted>
    <app_adc_conf.voltage2_inverted>1</app_adc_conf.voltage2_inverted>
    <app_adc_conf.throttle_exp>-0.5</app_adc_conf.throttle_exp>
    <app_adc_conf.throttle_exp_brake>0</app_adc_conf.throttle_exp_brake>
    <app_adc_conf.throttle_exp_mode>2</app_adc_conf.throttle_exp_mode>
    <app_adc_conf.ramp_time_pos>0.3</app_adc_conf.ramp_time_pos>
    <app_adc_conf.ramp_time_neg>0.1</app_adc_conf.ramp_time_neg>
    <app_adc_conf.multi_esc>1</app_adc_conf.multi_esc>
    <app_adc_conf.tc>0</app_adc_conf.tc>
    <app_adc_conf.tc_max_diff>3000</app_adc_conf.tc_max_diff>
    <app_adc_conf.update_rate_hz>500</app_adc_conf.update_rate_hz>
    <app_uart_baudrate>115200</app_uart_baudrate>
    <app_chuk_conf.ctrl_type>1</app_chuk_conf.ctrl_type>
    <app_chuk_conf.hyst>0.15</app_chuk_conf.hyst>
    <app_chuk_conf.ramp_time_pos>0.4</app_chuk_conf.ramp_time_pos>
    <app_chuk_conf.ramp_time_neg>0.2</app_chuk_conf.ramp_time_neg>
    <app_chuk_conf.stick_erpm_per_s_in_cc>3000</app_chuk_conf.stick_erpm_per_s_in_cc>
    <app_chuk_conf.throttle_exp>0</app_chuk_conf.throttle_exp>
    <app_chuk_conf.throttle_exp_brake>0</app_chuk_conf.throttle_exp_brake>
    <app_chuk_conf.throttle_exp_mode>2</app_chuk_conf.throttle_exp_mode>
    <app_chuk_conf.multi_esc>1</app_chuk_conf.multi_esc>
    <app_chuk_conf.tc>0</app_chuk_conf.tc>
    <app_chuk_conf.tc_max_diff>3000</app_chuk_conf.tc_max_diff>
    <app_chuk_conf.use_smart_rev>1</app_chuk_conf.use_smart_rev>
    <app_chuk_conf.smart_rev_max_duty>0.07</app_chuk_conf.smart_rev_max_duty>
    <app_chuk_conf.smart_rev_ramp_time>3</app_chuk_conf.smart_rev_ramp_time>
    <app_nrf_conf.speed>1</app_nrf_conf.speed>
    <app_nrf_conf.power>3</app_nrf_conf.power>
    <app_nrf_conf.crc_type>1</app_nrf_conf.crc_type>
    <app_nrf_conf.retry_delay>0</app_nrf_conf.retry_delay>
    <app_nrf_conf.retries>3</app_nrf_conf.retries>
    <app_nrf_conf.channel>76</app_nrf_conf.channel>
    <app_nrf_conf.address__0>198</app_nrf_conf.address__0>
    <app_nrf_conf.address__1>199</app_nrf_conf.address__1>
    <app_nrf_conf.address__2>0</app_nrf_conf.address__2>
    <app_nrf_conf.send_crc_ack>1</app_nrf_conf.send_crc_ack>
    <app_pas_conf.ctrl_type>1</app_pas_conf.ctrl_type>
    <app_pas_conf.sensor_type>0</app_pas_conf.sensor_type>
    <app_pas_conf.pedal_rpm_start>10</app_pas_conf.pedal_rpm_start>
    <app_pas_conf.pedal_rpm_end>120</app_pas_conf.pedal_rpm_end>
    <app_pas_conf.invert_pedal_direction>0</app_pas_conf.invert_pedal_direction>
    <app_pas_conf.magnets>24</app_pas_conf.magnets>
    <app_pas_conf.use_filter>1</app_pas_conf.use_filter>
    <app_pas_conf.current_scaling>0.08</app_pas_conf.current_scaling>
    <app_pas_conf.ramp_time_pos>0.3</app_pas_conf.ramp_time_pos>
    <app_pas_conf.ramp_time_neg>0.2</app_pas_conf.ramp_time_neg>
    <app_pas_conf.update_rate_hz>500</app_pas_conf.update_rate_hz>
    <imu_conf.type>1</imu_conf.type>
    <imu_conf.mode>0</imu_conf.mode>
    <imu_conf.filter>0</imu_conf.filter>
    <imu_conf.accel_lowpass_filter_x>0</imu_conf.accel_lowpass_filter_x>
    <imu_conf.accel_lowpass_filter_y>0</imu_conf.accel_lowpass_filter_y>
    <imu_conf.accel_lowpass_filter_z>0</imu_conf.accel_lowpass_filter_z>
    <imu_conf.gyro_lowpass_filter>0</imu_conf.gyro_lowpass_filter>
    <imu_conf.sample_rate_hz>200</imu_conf.sample_rate_hz>
    <imu_conf.use_magnetometer>1</imu_conf.use_magnetometer>
    <imu_conf.accel_confidence_decay>1</imu_conf.accel_confidence_decay>
    <imu_conf.mahony_kp>0.3</imu_conf.mahony_kp>
    <imu_conf.mahony_ki>0</imu_conf.mahony_ki>
    <imu_conf.madgwick_beta>0.1</imu_conf.madgwick_beta>
    <imu_conf.rot_roll>0</imu_conf.rot_roll>
    <imu_conf.rot_pitch>0</imu_conf.rot_pitch>
    <imu_conf.rot_yaw>0</imu_conf.rot_yaw>
    <imu_conf.accel_offsets__0>0</imu_conf.accel_offsets__0>
    <imu_conf.accel_offsets__1>0</imu_conf.accel_offsets__1>
    <imu_conf.accel_offsets__2>0</imu_conf.accel_offsets__2>
    <imu_conf.gyro_offsets__0>0</imu_conf.gyro_offsets__0>
    <imu_conf.gyro_offsets__1>0</imu_conf.gyro_offsets__1>
    <imu_conf.gyro_offsets__2>0</imu_conf.gyro_offsets__2>
</APPConfiguration>

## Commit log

2025-02-07 Some more info. Still a lot to filter down
2025-02-22 Add lots of things
    [1_declaracion_propuesta_valor.xlsx]
2025-02-22 Add cad folder
    I'm about to check dimensions and try laser-cut chassis
    [10in_hub_wheel.step, 14in QS273 6kW Scooter.SLDPRT, 14in QS273 6kW Scooter.stp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]
2025-02-24 Improve cad
    [Flat pattern - chassis.DXF, chassis.DXF, chassis.SLDDRW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]
2025-02-24 Add step files for chassis
    Still have to validate distance between pedal hangers
    [chassis.SLDPRT, chassis_hanger_interface.STEP, chassis_top.STEP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]
2025-03-04 Prepare dxf, step and pdf for laser cut send
    [chassis.SLDPRT, chassis_1.DXF, chassis_1.SLDDRW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]
2025-03-10 Cad dimensions fixed
    [chassis.SLDPRT, lid.SLDPRT, ueuc10.SLDASM]
2025-03-11 Change names
    [14in QS273 6kW Scooter.SLDPRT, 14in QS273 6kW Scooter.stp[1].sldprt, 14in QS273 6kW Scooter.stp[2].sldprt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]
2025-03-15 Add laser cut order
    [EUC_C1.STEP, EUC_C1_flat.STEP, EUC_C1_lines.DXF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]
2025-03-17 Add deliverable 2, explorer
    [2_hypotheses_and_mvp.xlsx]
2025-03-31 Update meeting 3 mentoring
    [PEF OL.xlsx]
2025-04-07 Move explorer to private folder, put public info here
    [1_declaracion_propuesta_valor.xlsx, 2_hypotheses_and_mvp.xlsx, PEF OL.xlsx]
2025-04-17 Follow semantic versioning with CW as CyberWheel shorthand
    [14in QS273 6kW Scooter.SLDPRT, 14in QS273 6kW Scooter.stp[1].sldprt, 14in QS273 6kW Scooter.stp[2].sldprt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]
2025-04-18 Rename cad files
    [14in QS273 6kW Scooter.SLDPRT, 14in QS273 6kW Scooter.stp[1].sldprt, 14in QS273 6kW Scooter.stp[2].sldprt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]
2025-04-21 Update bom
    [Plantilla corte la╠üser Archicercle - Instrucciones.dxf, bom.xlsx]
2025-04-21 Update before formatting windows
    [bom.xlsx]
2025-04-24 Add video pitch
2025-06-13 Update after laser v1 failed
    [EUC_C1.STEP, EUC_C1_flat.STEP, EUC_C1_lines.DXF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]
2025-10-07 Add MkDocs documentation and VESC Refloat troubleshooting notes
    Documentation:
    - Set up MkDocs with Material theme for project documentation
    - Organize docs with Getting Started, Design, Releases, and References sections
    - Configure GitHub Actions for auto-deployment to GitHub Pages
    - Use uv for Python dependency management
    - Add self-contained assets structure in docs/assets/
    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
2025-10-07 Update todo.md with VESC balance app notes
2025-10-07 Update to modern GitHub Pages deployment with Actions
    Switch from legacy mkdocs gh-deploy to official GitHub Pages Actions:
    - Separate build and deploy jobs
    - Uses upload-pages-artifact and deploy-pages actions
    - No git push to gh-pages branch required
    - Uses GitHub Pages API for deployment
2025-10-07 Convert BOM to markdown and add openpyxl dependency
    - Replace Excel BOM with markdown tables in cw1.1 release
    - Add manufacturing cost breakdown (1,912€ with purchased battery)
    - Add battery sub-components table (528€ if self-manufactured)
    - Include cost summary with different scenarios
    - Add openpyxl to dependencies for future Excel processing
    [bom.xlsx]
2025-11-10 Add prominent pitch video section to README
    Make the pitch video more visible by adding a dedicated section with emoji icon, matching the documentation section style.
2025-12-17 Document cw1.1 current test setup
2025-12-17 Add VESC docs and config exports
    [vesc_appconf.xml, vesc_appconf_2025-12-13--02.xml, vesc_appconf_2025-12-16_first_ride.xml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]
2025-12-26 New design in fusion 360 with the lid finished
    [chassis.SLDPRT, chassis1.SLDPRT, chassis_1.SLDDRW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]
2025-12-26 Add step of the pedal hanger, useful to transfer to fusion
    [pedal_hanger_inmotion.STEP]
2025-12-27 Add .step for cw1.2
    [nylonove_pedals.STEP]
2025-12-29 Add lid designs
    [#cw1.2_lid_flat.dxf, cw1.2_lid.step, cw1.2_lid_flat.dxf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]
